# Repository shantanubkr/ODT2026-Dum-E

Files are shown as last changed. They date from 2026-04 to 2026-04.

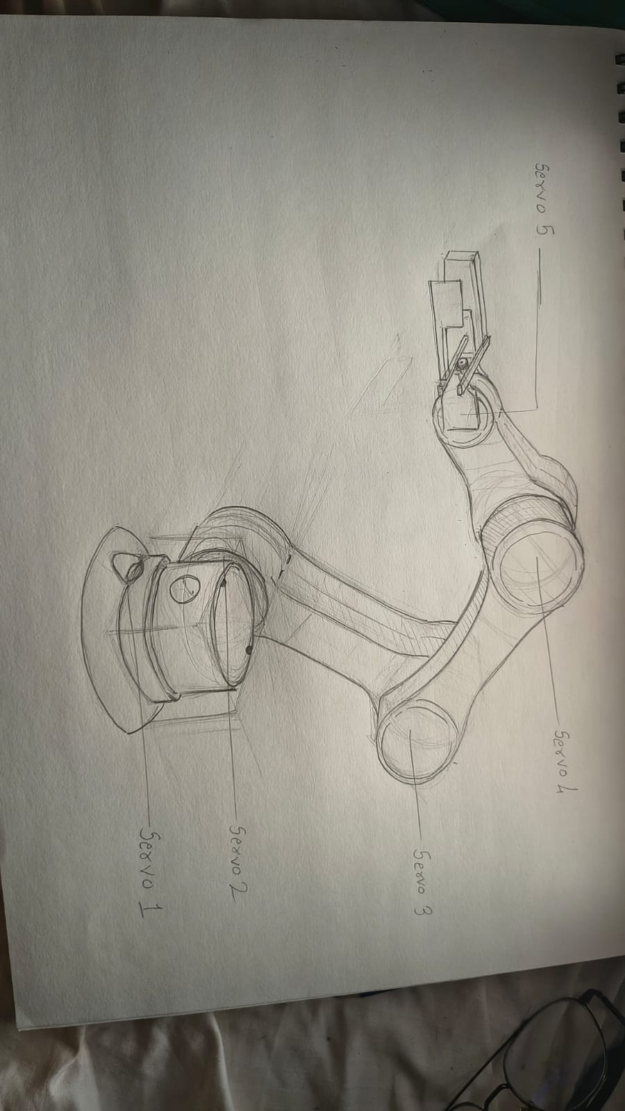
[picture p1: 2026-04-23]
Media/Week2/WhatsApp Image 2026-04-23 at 18.40.53.jpeg

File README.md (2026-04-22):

**Project Title**

dum-e

**📌 Project Overview**

Dum-E is a custom-built, articulated robotic arm.

It operates using the ROS 2 Humble software framework to handle complex kinematics and precise, multi-joint motion control. Physically, the arm is driven by a stable S-25-5 power supply to manage heavy actuator loads and features an integrated ESP32-CAM module that provides real-time visual telemetry and spatial awareness.

**📂 Repository Structure**
1. Electronics Details
2. Mechanical Details
3. Software Details
4. Project Documents
5. Media

**⚙️ How to Navigate This Repository**

Electronics Details → Circuit, components justification

Mechanical Details → Sketches, CAD, and fabrication

Software Details → Code, logic, and implementation

Project Documents → Design thinking, planning, testing

Media → Weekly progress and final output

**👥 Team Members**
Avyukt and shantanu

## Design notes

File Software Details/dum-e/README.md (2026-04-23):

# DUM-E

DUM-E is an ESP32-based robotic arm / assistant inspired by Marvel’s DUM-E. On-robot: **ESP32**, **five servos**, and **power**. **Camera and higher-level software** (dashboard, vision, optional ROS) run on a **laptop**. This repository holds the MicroPython firmware, deploy tooling, and desktop app.

The device runs **MicroPython** on an ESP32. You edit code locally in **Cursor** and deploy it to the board (for example with `mpremote` and the scripts under `deploy/`).

### Setup (host)

1. **One-shot host install** (creates `.venv`, installs `mpremote`):

   ```bash
   cd "/path/to/Software Details/dum-e"
   ./setup-host.sh
   ```

2. **Push code to the ESP32 and reset** — `deploy/common.sh` picks a serial port automatically (`DUM_E_MPREMOTE_PORT` if set and valid, else `/dev/cu.usbserial-0001`, else first `cu.usbserial*` / `wchusbserial*` / `SLAB`):

   ```bash
   cd deploy
   ./sync.sh          # same as ./upload.sh && ./run.sh
   ```

3. **Open the REPL** (quit anything else using the USB serial port first — Thonny, another `mpremote`, etc.):

   ```bash
   cd deploy
   ./repl.sh
   ```

4. **Manual split** (same as before): `./upload.sh` then `./run.sh`.

5. The scripts prefer `.venv`’s `python -m mpremote` (see `deploy/common.sh`).

6. **`mpremote: failed to access (it may be in use…)`** — another app has the port, **or** `DUM_E_MPREMOTE_PORT` was empty/wrong. Fix: close other serial tools, `unset DUM_E_MPREMOTE_PORT` for auto-detect, or `export DUM_E_MPREMOTE_PORT=/dev/cu.usbserial-0001`.

7. If you moved the repo and see `bad interpreter` from `mpremote`, remove `.venv` and run `./setup-host.sh` again.

8. **`termios.error: (22, 'Invalid argument')` when `mpremote` connects** — pyserial could not apply serial settings on that `/dev/cu.*` node (common on macOS with some USB‑UART chips or when the wrong device is selected). Quit the **desktop app**, **Thonny**, and any **serial monitor** using the same port; unplug/replug the ESP32; run `ls /dev/cu.*` and set **`export DUM_E_MPREMOTE_PORT=/dev/cu.…`** to the real motor board; try another **USB cable/port** (data cable, not charge‑only); update the vendor driver (Silicon Labs CP210x, WCH CH34x, etc.) for your OS version; then **`pip install -U pyserial mpremote`** in `.venv`. If **`screen /dev/cu.… 115200`** also fails, the issue is outside Python (cable, hub, or driver).

## Current focus

1. Foundation (project layout, config, docs)
2. Motion (servos, named poses, smooth stepping)
3. Safety (limits, emergency stop)
4. Vision & UX on the laptop (camera, dashboard, optional ROS)
5. Higher-level behavior (state machine, commands, personality-style behaviors)
6. **Table / pick calibration (USB `pose_deg` jog):** see **`calibration/README.md`**

## Project structure

| Path | Role |
|---|---|
| `src/` | MicroPython application: entrypoint, config, drivers, modules, interfaces |
| `docs/` | Hardware inventory, architecture, state machine notes |
| `deploy/` | Helper scripts to upload `src/` to the device and reset the board |
| `requirements.txt` | Host Python deps (`mpremote`); use with project `.venv` |

## Next steps

- Finalize wiring and tune `src/pins.py` + per-joint PWM limits in `src/config.py`.
- Calibrate motion and grow the state machine / command path as behaviors stabilize.

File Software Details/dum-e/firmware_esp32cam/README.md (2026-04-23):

# ESP32-CAM: MJPEG tuning (Arduino + reference for MicroPython)

## Arduino (`esp32-camera` / `esp_camera` init)

In your `setup()` (before `esp_camera_init(&config);`), set:

```c
config.frame_size = FRAMESIZE_QVGA;   // 320×240 — stable, low bandwidth
config.jpeg_quality = 20;             // 0–63; **higher** = more compression / smaller files (less lag)
```

Use the value `20` for a smaller per-frame payload than very low values (e.g. 5–10) which can produce **larger** JPEGs in busy scenes, depending on the sensor driver.

`jpeg_quality` semantics follow **Espressif `esp32-camera`**: see your board package’s `sensor_t` and examples under **Examples → ESP32 → Camera → CameraWebServer**.

## MicroPython (this repo)

`desktop_app/launch_cam.py` pastes a stream server that uses `camera.FRAME_QVGA` and, if supported, `quality=20` in `camera.init(...)`. If the board firmware rejects `quality=`, the script falls back to the two-argument `init` only.

## Laptop / OpenCV

Use `desktop_app/services/camera_stream.py` — **FFmpeg** backend, **buffer size 1**, corrupt frames return `None` so vision does not block on a bad chunk.

See `firmware_esp32cam/arduino_mjpeg_config_snippet.ino` for a drop-in `config` block.

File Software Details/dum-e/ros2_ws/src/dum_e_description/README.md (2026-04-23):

# dum_e_description

ROS 2 Humble package: **URDF/xacro**, **meshes**, and Gazebo extras for DUM-E (4 revolute joints; matches firmware four-DOF arm).

## Contents

| Path | Purpose |
|---|---|
| `urdf/dum-e.xacro` | Main robot (Revolute 7–10); includes materials, transmissions, Gazebo |
| `urdf/*.xacro` | Includes |
| `meshes/*.stl` | Visual/collision meshes (mm STLs, scale 0.001 in xacro) |

## Build

From repo root on Ubuntu / WSL2 (ROS 2 Humble sourced):

```bash
./scripts/build_ros.sh
```

Or from `ros2_ws/`:

```bash
source /opt/ros/humble/setup.bash
colcon build --packages-select dum_e_description
source install/setup.bash
```

## Visualize (`robot_state_publisher` + sliders + RViz)

Do **not** run this at the same time as `dum_e_state_manager` — both publish `/joint_states`.

```bash
source install/setup.bash
ros2 launch dum_e_description view_robot.launch.py
```

## Manual RViz (no launch file)

```bash
ros2 run xacro xacro $(ros2 pkg prefix dum_e_description)/share/dum_e_description/urdf/dum-e.xacro > /tmp/dum_e.urdf
ros2 run robot_state_publisher robot_state_publisher --ros-args -p robot_description:="$(cat /tmp/dum_e.urdf)"
```

## Joint ↔ mesh filenames

Meshes were renamed from informal CAD STL filenames to match the xacro:

- `Base.stl` → `base_link.stl`
- `Waist.stl` → `Waist_1.stl`
- `Upper_arm.stl` → `Upper_arm_1.stl`
- `Forearm.stl` → `Forearm_1.stl`
- `Hand.stl` → `Hand_1.stl`
- `end_effector.stl` — unused in current `dum-e.xacro` (reserved for a future tool)

## Note on ROS 1 transmissions

`dum-e.trans` uses ROS 1 `hardware_interface` names. For real Gazebo / ros2_control you’ll need to update or replace transmissions later.

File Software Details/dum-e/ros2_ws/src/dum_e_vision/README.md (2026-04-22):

# `dum_e_vision` (ROS 2)

Publishes **`geometry_msgs/Point`** on **`/dume/target_coord`**: **x, y** = blob centroid (px), **z** = contour area. Consumed by `desktop_app/track_target_node.py`.

## Modes

| Param | Gazebo / sim | Real ESP32-CAM (OpenCV) |
|---|---|---|
| `use_simulation` | `true` | `false` (default) |
| Input | `camera_image_topic` (default `/camera/image_raw`) | `stream_url` (e.g. `http://<ip>:81/stream`) |
| Drive | one callback per `sensor_msgs/Image` | timer at `publish_rate_hz` (default 10) |

## Build (ROS 2 Humble)

```bash
cd ros2_ws
source /opt/ros/humble/setup.bash
colcon build --packages-select dum_e_vision
source install/setup.bash
```

## Run

**Real camera:**

```bash
ros2 run dum_e_vision vision_node --ros-args \
  -p use_simulation:=false \
  -p stream_url:=http://192.168.1.100:81/stream \
  -p target_color:=red
```

**Gazebo (example):**

```bash
ros2 run dum_e_vision vision_node --ros-args \
  -p use_simulation:=true \
  -p camera_image_topic:=/camera/image_raw
```

Requires: **OpenCV** (`python3-opencv` / `cv_bridge`).

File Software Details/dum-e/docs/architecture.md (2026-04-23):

# Architecture

Firmware keeps **hardware** in one layer and **policy / behavior** in another. The ESP32 entrypoint stays **thin**: construct objects, `boot()`, then a `loop()` that polls serial, updates motion, behaviors, and activity timeouts.

## Repository layout (firmware)

| Path | Role |
|---|---|
| `src/main.py` | Entry: `StateMachine`, `IntentParser`, `BehaviorEngine`, `SafetyManager`, `MotionController`, `CommandRouter`; non-blocking stdin; optional physical buttons when `USE_PHYSICAL_BUTTONS` is True. |
| `src/config.py` | Timing, joint limits, PWM calibration, feature flags (e.g. `USE_PHYSICAL_BUTTONS`). |
| `src/pins.py` | GPIO for servos and optional `BTN_*` pins. |
| `src/backend/` | **`command_schema.py`** — `Actions`, `Command`. **`command_router.py`** — `CommandRouter` (routes `Command` to motion, safety, behaviors, status/history) and **`build_command_from_parse_result()`** (maps parser output to `Command`). |
| `src/modules/` | **`state_machine.py`** — `States` and transitions. **`command_parser.py`** — text → `{type, command, args}`. **`intent_parser.py`** — extends parser with **sentiment** (`GREET` / `BYE` / `HAPPY` / `SAD` / `NEUTRAL`) for expression behaviors. **`motion_controller.py`** — five PWM servos, named poses (`home`, `ready`, `down`). **`behavior_engine.py`** — idle / greeting / thinking + `express_*` behaviors. **`safety_manager.py`** — emergency stop (+ optional fault latch); `can_move()` gates motion in the router. |
| `src/drivers/` | **`servo.py`** — `Servo` (MicroPython `PWM` hobby servo). **`panel_button.py`** — `Button` (debounced) if **`USE_PHYSICAL_BUTTONS`** is enabled. Vision runs on the **laptop** (`desktop_app/`), not on the ESP32. |
| `src/utils/` | Logging, timers — no hardware imports. |
| `deploy/` | Host scripts (`mpremote`) — not flashed to the device. |

## Host / desktop (not on the ESP32)

| Path | Role |
|---|---|
| `desktop_app/` | Dashboard and **`dum_e_runtime.py`**: imports the same `backend` + `modules` under CPython (with a small time shim), optional **`LaptopMotionController`** sim, or **`RobotBridge`** to publish string commands to ROS 2 (`/dum_e_command`) when not skipping ROS. |
| `desktop_app/services/robot_bridge.py` | **`RobotBridge`** — maps high-level `Command` to **BLE NUS** ( **`DUM_E_BLE=1`** ), **or** USB serial ( **`DUM_E_SERIAL_PORT`** ), **or** ROS `ros2 topic pub` on **`/dum_e_command`** (one path); **not** flashed to the ESP32. |

## Data flow (firmware)

1. **stdin line** → `IntentParser.parse()` → sentiment may run **`BehaviorEngine.run_behavior()`** for `express_*` → **`build_command_from_parse_result()`** → **`CommandRouter.route()`**.
2. **`MotionController.update()`** each loop tick interpolates toward target angles (smooth motion).
3. **`BehaviorEngine.update()`** runs the current behavior tick (expressions, timed greeting/thinking).
4. **`update_activity_state()`** (firmware) or **`_update_desktop_inactivity()`** (desktop) moves **ACTIVE → SLEEP** after **`SLEEP_TIMEOUT_MS`**; activity resets the timer. There is no intermediate **IDLE** machine state.

## Principles

1. **Drivers** talk to GPIO/PWM only; they do not encode “why” the arm moves.
2. **Modules + backend** encode commands, safety, and behaviors.
3. **`main.py`** wires objects and runs the loop — minimal logic.

New on-robot hardware belongs in `src/drivers/`; new command or policy behavior in `src/modules/` or `src/backend/` as appropriate.

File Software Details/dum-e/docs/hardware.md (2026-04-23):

# Hardware inventory

This doc matches the **current build**: **ESP32**, **four PWM servos** (arm only), **dedicated servo power**, and a **camera** used with **laptop-side** vision (`desktop_app/`). CAD / ROS URDF and meshes: **`ros2_ws/src/dum_e_description/`** (canonical).

**CAD vs firmware:** The URDF has **four** revolute joints (`Revolute 7`–`10`); firmware joint order matches (**waist**, **upper_arm**, **forearm**, **hand**).

Update the **Status** column as you wire and test: `planned` → `wired` → `tested`.

---

## Controllers & compute

| Component | Qty | Notes | Status |
|---|-----|---|---|
| ESP32 DevKit (e.g. 30-pin) | 1 | MicroPython; PWM to servos; USB serial for deploy and dashboard | planned |
| Laptop | 1 | Dashboard, speech, vision, optional ROS — not on the robot PCB | planned |

---

## Motion — four PWM servos (arm)

Firmware uses **four** hobby servos (50 Hz) for the arm. The **base** link in CAD has **no motor**; rotation starts at **waist**.

| Servo # | Firmware / CAD name | Role |
|---|---|---|
| 1 | `waist` | Base rotation (base ↔ waist) |
| 2 | `upper_arm` | Waist ↔ upper arm |
| 3 | `forearm` | Upper arm ↔ forearm |
| 4 | `hand` | Forearm ↔ hand (wrist) |

Joint order in code and logs: `waist`, `upper_arm`, `forearm`, `hand`.

| Component | Qty | Notes | Status |
|---|-----|---|---|
| Hobby / RC servo (PWM), arm | 4 | Per link torque | planned |

GPIO defaults are in `src/pins.py` (`SERVO_WAIST`–`SERVO_HAND`, or PCA9685 channels when `USE_PCA9685` is True). **Change there when wiring is final.**

Mechanical **upright / home** is defined in `src/config.py` as **`UPRIGHT_POSE_DEG`** (and `robot_kinematics.UPRIGHT_FIRMWARE_DEG`): by default all joints **90°** after PWM calibration so the arm stands stacked neutral.

**Control:** Default build has **no** physical panel buttons (`USE_PHYSICAL_BUTTONS = False` in `config.py`). Use **desktop dashboard**, **USB serial**, or **REPL**.

---

## Power

| Component | Qty | Notes | Status |
|---|-----|---|---|
| USB cable / 5 V from host | 1 | Powers and programs the ESP32 | planned |
| 5 V rail for servos (bench supply, BEC, or buck) | 1 | Servos draw high peak current; **do not** power servos from the ESP32 3.3 V regulator | planned |
| Common ground | 1 | ESP32 GND tied to servo supply GND for valid PWM | planned |
| Buck / LDO (optional) | 0–1 | If logic runs from a higher-voltage main rail | planned |

---

## Camera & vision

| Component | Qty | Notes | Status |
|---|-----|---|---|
| Camera module (e.g. USB webcam or board-mounted module) | 1 | Feeds the **laptop**; processing lives in `desktop_app/` (OpenCV, optional idle look-at). **ESP32 firmware does not run vision.** | planned |

---

## Passive, mechanical, prototyping

| Component | Qty | Notes | Status |
|---|-----|---|---|
| Capacitors | as needed | Bulk/decoupling on servo supply if long leads or noisy supply | planned |
| Resistors | as needed | e.g. pull-ups if you add I2C later | planned |
| Jumper wires | — | Dupont / solid core | planned |
| Breadboard / perfboard | — | Bring-up | planned |

---

## ROS / simulation (not on the robot PCB)

| Item | Notes |
|---|---|
| `ros2_ws/src/dum_e_description/` | Canonical URDF, meshes, launch for RViz |
| `dum-e.trans` | ROS 1–style transmissions; replace with **ros2_control** if you simulate in Gazebo later |

---

## Components table (electronics documentation)

| Component | Quantity | Purpose | Justification |
|---|---|---|---|
| ESP32 development board | 1 | Run MicroPython, PWM for servos, USB for programming and serial dashboard | Single board with enough GPIO; matches firmware and deploy flow (`mpremote`). |
| Hobby (RC) servo motors | 4 | Arm joints (waist … hand) | PWM servos per mechanical design. |
| 5 V power source for servos | 1 | Supply motor current without loading the ESP32 regulator | Peak current; dedicated rail avoids brownouts. |
| Common electrical ground | 1 (net) | ESP32 GND to servo supply GND | Required for valid PWM references. |
| USB cable | 1 | Power and flash ESP32 from PC | For `deploy/` scripts and REPL. |
| Camera (with laptop) | 1 | Vision / idle behaviors on host | Processing in `desktop_app/`, not on ESP32. |
| Jumper wires / breadboard | as needed | Bring-up | Standard prototyping. |

---

## Placeholders

Add rows for **panel buttons**, **E-stop**, **encoders**, or **LEDs** only if those become part of the wired build.

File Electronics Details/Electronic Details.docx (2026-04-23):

# Electronics Documentation

### 1. Electronics Block Diagram

Show signal and power flow

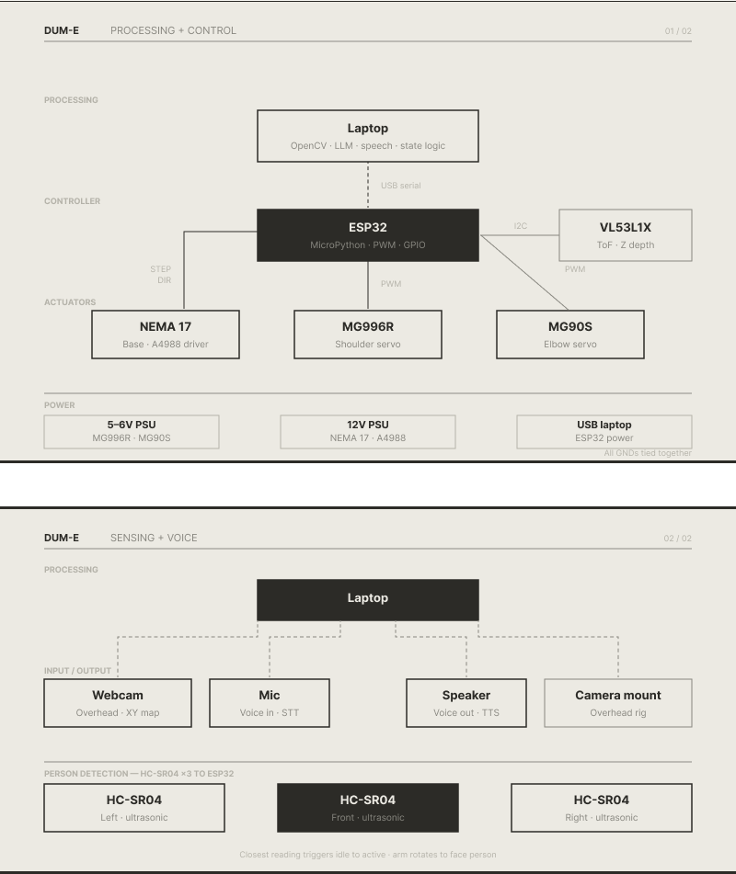
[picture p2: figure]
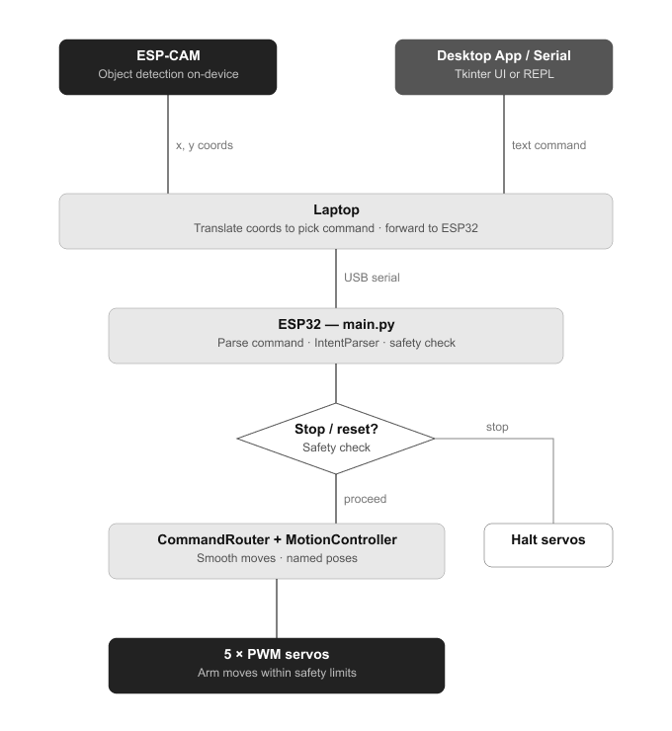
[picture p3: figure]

### 2. Components Table

Component | Quantity | Purpose | Justification
ESP32 development board | 1 | Run MicroPython, PWM for five servos, USB for programming and serial control | One MCU with enough GPIO for five PWM channels and USB; matches firmware and deploy workflow.
servo motors: mg996R Mg90s sg90s | 5 | Move waist, upper arm, forearm, wrist, and gripper | Settable angles per joint for a small arm
Jumper wires / breadboard | As needed | Prototype connections before final harness | Standard for lab wiring and iteration.
5v Power Supply | 1 | To power the components | Required for energy
PCA9685 | 1 | To control the servos without fluctuations | Required for the servos to avoid current fluctuations
Esp 32 cam | 1 | To map the objects on the table | Required to map the surface and object detection

Justification is important

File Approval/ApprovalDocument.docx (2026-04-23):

ODT Summative 2

Idea Brief :

DUM-E is an interactive robotic arm inspired by the Iron Man assistant, designed to respond to natural voice commands and interact with its surroundings in a human-like manner. The system combines speech recognition, computer vision, and robotic motion to create an intuitive and engaging user experience.

Users can speak to DUM-E in complete sentences (e.g., “pick up the red object” or “go home”), which are processed using local speech-to-text and interpreted into actionable commands. A top-mounted camera detects objects on the workspace using color-based vision, identifies their position, and maps them to real-world coordinates. The robotic arm then moves precisely to the object, picks it up, and performs the required action.

Beyond task execution, DUM-E is designed to feel expressive and interactive. It reacts to greetings, commands, and user behavior through movement and sound-based feedback, creating a personality-driven interaction rather than a purely functional system.

The goal of this project is to build a system that seamlessly integrates voice interaction, perception, and motion into a cohesive robotic assistant that is both functional and engaging.

Basic Idea Sketch :

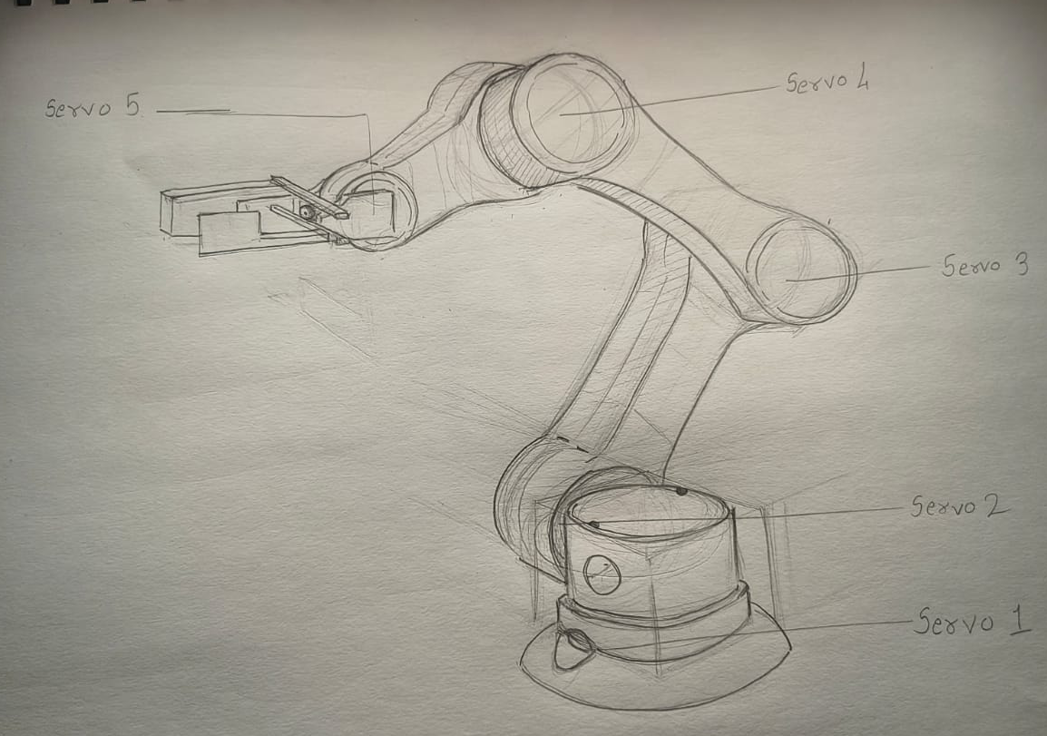
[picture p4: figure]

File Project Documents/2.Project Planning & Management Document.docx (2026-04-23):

# Project Planning & Management Document

### 1. Project Overview

- Project Title: Dum-E
- Team Members & Roles:
  - Shantanu Borkar - Software Guy
  - Avyukt Srivastava - Hardware Guy
- Brief Description (2–3 lines)
  - DUM-E is an interactive robotic arm that responds to natural voice commands and uses a camera to detect and locate objects in its workspace. It combines speech recognition, computer vision, and motion to perform actions like picking and placing objects. The system focuses on creating an intuitive and engaging human-robot interaction experience.

### 2. Team Roles & Responsibilities

Member Name | Role | Responsibilities
Shantanu Borkar | Software Guy | Designed the overall system architecture (voice → vision → motion) Built the desktop app for interaction and control Implemented speech-to-text and command interpretation Developed color-based object detection using the camera Integrated command routing with the robot hardware Tested, debugged, and ensured system stability
Avyukt Srivastava | Hardware Guy | Designed and modeled the robotic arm components (3D design and sizing) 3D printed parts and handled assembly of the full structure Defined joint dimensions, ranges, and mechanical mapping Integrated servo motors, gripper mechanism, and physical joints Set up and connected ESP32 and ESP32-CAM hardware Managed wiring, power distribution, and overall hardware testing and calibration

👉 Clearly define who is responsible for what (software, electronics, documentation, etc.)

### 3. Project Timeline & Milestones

Week | Goals | Deliverables | Status
Week 0 | Finalize project idea and scope Define system architecture (voice, vision, motion) Split roles (software / hardware) | Idea brief and architecture plan Basic hardware and software requirements list | Completed
Week 1 | Set up robotic arm hardware base Build initial desktop app structure Implement basic command flow (manual / button-based) | Working robotic arm (basic movement) Initial software framework and control interface | Completed
Week 2 | Integrate speech-to-text for voice commands Build AI interpreter for command parsing Set up camera and implement color-based object detection | Voice-controlled commands working Camera detecting objects and returning coordinates | Completed
Week 3 | Integrate vision with motion (pick object flow) Add sound-based feedback and interaction polish Test full pipeline (voice → detection → action) | End-to-end working system Stable interaction and demo-ready prototype | Not completed

👉 Break project into weekly achievable goals

### 4. Weekly Progress Log

### Week 0

Planned Tasks:

- Finalize idea and system architecture
- Define roles and required components

Completed Tasks:

- Decided on DUM-E concept (voice + vision + motion)
- Designed overall system flow
- Listed hardware and software requirements

Challenges Faced:

- Scope was initially too broad (wanted too many features)

Solutions:

- Reduced scope to core features: voice control + object detection + pick action

Next Steps:

- Start hardware build and basic software setup

### Week 1

Planned Tasks:

- Build robotic arm structure
- Set up initial software control

Completed Tasks:

- Designed and 3D printed arm parts
- Assembled basic arm structure
- Set up ESP32 and basic motor control
- Created initial desktop app structure

Challenges Faced:

- Planned to use a stepper motor for 360° base rotation but it wasn’t ordered in time

Solutions:

- Switched to using a servo-based setup for the base instead

Next Steps:

- Improve control system and start integrating interaction

### Week 2

Planned Tasks:

- Implement voice commands
- Set up camera and object detection
- Work on coordinate mapping

Completed Tasks:

- Integrated local speech-to-text (Whisper)
- Built AI interpreter for commands
- Implemented basic color-based detection
- Created digital simulations for object picking and coordinate mapping

Challenges Faced:

- Voice commands initially didn’t work reliably with natural sentences
- Coordinate mapping and simulated pick actions were inconsistent

Solutions:

- Improved interpreter logic to handle full sentences instead of exact keywords
- Refined mapping logic and tested through simulations instead of hardware

Next Steps:

- Connect vision with motion and stabilize the full pipeline

### Week 3

Planned Tasks:

- Integrate all systems (voice → vision → motion)
- Test full working prototype
- Add interaction feedback

Completed Tasks:

- Built end-to-end pipeline in software (voice → detect → action)
  - Action failed
- Added sound-based feedback for interaction
- Finalized system for demo

Challenges Faced:

- Physical testing was delayed; most testing was done digitally until the last day
- Could not implement additional sensors (ultrasonic/LDR) for distance detection due to time constraints
- Limited time for real-world calibration and tuning

Solutions:

- Focused on ensuring digital pipeline worked reliably
- Simplified features to ensure core system was functional

Next Steps:

- Improve physical testing, calibration, and sensor integration in future iterations

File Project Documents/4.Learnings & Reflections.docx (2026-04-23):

# Learnings & Reflections Document

## 1. Team Reflection

How did the team work together?
The team had clear role distribution, with members focusing on hardware, software, and integration. Collaboration was strong during building phases, but less consistent during testing and validation.

What worked well?

- Clear division of responsibilities
- Fast execution and willingness to build quickly
- Good problem-solving when issues were identified

What could be improved?

- Lack of continuous testing throughout development
- We kept adding features instead of validating what was already built
- Poor integration planning between hardware and software
- Needed more structured checkpoints instead of last-minute fixes

## 2. Technical Reflection

Key technical challenges

- Servo motors behaving unpredictably due to signal and power issues
- System instability when multiple components were connected
- Voice commands not functioning reliably
- Difficulty in coordinate mapping and object pickup logic
- Final system integration failing under real conditions

What did you learn (hardware/software)?

- Testing individual components early is critical
- Hardware systems require stable power and clean signal separation
- Building multiple features without validation leads to system failure
- Integration is harder than building individual parts
- Real-world performance is very different from isolated testing

Mistakes & debugging experiences

- Biggest mistake: delaying testing until the end
- We kept stacking features without checking if the system still worked
- Debugging became overwhelming because too many things were broken at once
- We learned that small, incremental testing is far more effective than final-stage debugging

## 3. Design Reflection

Did the experience match your intention?
No. While the concept was strong, the final system did not perform as expected during the presentation due to lack of proper testing and refinement.

What would you improve?

- Follow a build → test → iterate cycle instead of continuous feature addition
- Prioritize reliability over adding new features
- Test in real-world conditions earlier, not just controlled setups
- Simplify the system before scaling complexity

User feedback insights

- The idea was appreciated, but execution felt incomplete
- Inconsistent behavior reduced confidence in the system
- A simpler but reliable system would have created a stronger impact

## 4. Personal Reflection

### Shantanu Borkar

  - What I learned I learned how to break down a robotics system into smaller working parts instead of trying to build everything at once. On the software side, I worked on writing control logic for servos using PWM and handling multiple actuators together. I also explored integrating features like text to speech for command feedback, basic coordinate mapping for movement logic, and object detection using the ESP32-CAM module.

I understood how important signal stability, proper grounding, and power distribution are when working with multiple servos and sensors. I also learned that hardware and software cannot be treated separately, both need to be tested together from early stages.

  - What I struggled with I struggled with scope control and kept adding features like voice input, object detection, and mapping without fully stabilizing the base system. This led to multiple issues stacking up at the same time.

Technically, I faced problems with servo jitter and unintended movements due to shared power lines and noisy signals. Integrating ESP32-CAM for object detection was also difficult because of limited processing and inconsistent outputs. The biggest challenge was system integration, getting all components like servos, camera, and logic to work together reliably.

  - What I am proud of I am proud that I took ownership of the system logic and kept pushing through technical issues instead of simplifying the project. I worked on implementing text to speech output, attempted coordinate-based movement, and integrated ESP32-CAM for object detection as part of the system.

Even though the final system was not stable during the presentation, I built and tested multiple complex components and understood where and why they failed. I now have a clearer understanding of real world constraints like power limitations, signal interference, and the importance of iterative testing in system design.

- Avyukt Srivastava
  - What I learned I learned how to structure a robotics system using ROS2 Humble by dividing it into different packages like dum_e_description, dum_e_controller, and dum_e_hardware. I also learned how to use colcon to build and manage these packages properly. Along with this, I gained practical experience in connecting software with hardware, including working with the ESP32-CAM module for vision and understanding how to manage power across the system.
  - What I struggled with I faced challenges with the power supply, especially while troubleshooting the S-25-5 unit to make sure it was providing stable voltage. I also struggled with the connection between hardware and software. Making sure ROS2 controllers could communicate properly with the physical components took a lot of debugging and testing.
  - What I am proud of I am proud that I was able to get all the main parts of the system working together, including the hardware, description, and controller packages. I also feel proud of building a strong base for the Dum-E project, taking it from just an idea to a working system that can be improved further.

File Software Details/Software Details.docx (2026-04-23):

# Software Documentation

## 1. Software overview

What the software does

- On the ESP32: Runs MicroPython firmware that reads text commands (USB serial), parses them, applies safety (e.g. stop/reset), updates a state machine, runs behaviors (idle, greetings, short “expression” motions), and drives five PWM servos through a motion controller (smooth moves to targets and named poses like home / ready / down).
- On the laptop (optional): A Python desktop app (Tkinter UI) sends the same style of commands to the board over USB serial and can optionally forward high-level actions to ROS 2 for coordination/visualization.
- ROS 2 (optional, Linux/WSL): URDF/meshes and tools like RViz describe and visualize the arm; they do not replace firmware on the robot.

Platforms & languages

Layer | Platform / stack
Robot firmware | MicroPython on ESP32
Deploy / REPL | Host Python 3 + `mpremote` (scripts under `deploy/`)
Desktop UI | CPython 3 + Tkinter (`desktop_app/`)
Simulation / viz | ROS 2 (e.g. Humble) + URDF/xacro (`ros2_ws/`) — optional

Not used in this codebase: MIT App Inventor, Bluetooth/BLE app path (control is USB serial by default).

## 2. System logic (simple flow)

Typical path: user uses the desktop app

1. User types a command or uses a control in the DUM-E Desktop app.
2. The app sends a line of text to the ESP32 over the USB serial port (same as typing into a serial terminal).
3. `main.py` reads the line; `IntentParser` classifies it (and may detect sentiment for expression motions).
4. `build_command_from_parse_result()` builds a `Command`; `CommandRouter` runs it (move home, pick/place poses, stop, reset, status, etc.).
5. `MotionController.update()` each loop tick moves servos toward targets; `BehaviorEngine.update()` runs timed/expression behaviors.
6. Servo PWM updates → arm moves (within software limits).

Typical path: direct serial / REPL (no desktop app)

7. User connects with `mpremote`, Thonny, or any serial monitor.
8. User sends a line ending in Enter.
9. Steps 3–6 are the same as above.

Optional: ROS bridge (when enabled on the laptop)

- The desktop runtime may map some commands to ROS 2 topic publishes (e.g. string commands for a state manager node), while the physical arm still follows firmware when the ESP32 is connected.

## 3. Flowchart (visual)


## 4. App flow — MIT App Inventor

Not applicable. This project does not use MIT App Inventor.

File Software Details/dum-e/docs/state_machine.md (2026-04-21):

# State machine

States are defined in **`src/modules/state_machine.py`** as **`States.*`** string constants. Use **`change_state()`** for transitions (logged); do not assign raw strings.

## States

| State | Meaning in code |
|---|---|
| `BOOT` | Initial value after `StateMachine()`; cleared on first **`boot()`** in `main.py` (or desktop init in **`dum_e_runtime.py`**) by transitioning to **`ACTIVE`**. |
| `ACTIVE` | Default “awake” running state after boot; user activity keeps the activity timer fresh. While behavior is **`"idle"`**, **`BehaviorEngine`** runs **curious wander** (motion every 2–5 s) when **`SafetyManager.can_move()`** allows. |
| `SAD` | **Mood** state after negative sentiment: **`express_sad`** animation, then **`sad_hold`** (slouch). No wander. Exits to **`ACTIVE`** on almost any routed command (except **`status`** / **`history`**) or on **GREET** / **HAPPY** / **BYE** sentiment. |
| `WORKING` | Set by **`CommandRouter`** for **`MOVE_TO`** when there is **no** named pose in metadata — placeholder path (“trajectory TBD” in logs). |
| `ERROR` | Legacy / reserved; **`STOP`** no longer lands here — use **`STOP_COOLDOWN`**. |
| `STOP_COOLDOWN` | After **`STOP`**: move to **`home`**, then when home is reached **`trigger_emergency_stop()`** and hold **10 s** (`STOP_COOLDOWN_MS`) with **no** other motion or commands (duplicate **`STOP`** ignored). Then estop clears automatically → **`ACTIVE`** + **`idle`** (wander enabled again). |
| `DATA_ERROR` | Bad serial / timeout / coords: call **`CommandRouter.route_data_fault(reason)`** — log, **`error_nod`** (waist shake), stub error sound log; **5 s** later (`DATA_ERROR_RECOVERY_MS`) auto **home** → **`ACTIVE`** + **`idle`**. Other commands ignored until recovery or **`RESET`**. |
| `SLEEP` | Entered when **`SLEEP_TIMEOUT_MS`** passes since last activity (unless already sleeping). **`STOP_COOLDOWN`**, **`DATA_ERROR`**, and **`ERROR`** return early so sleep logic does not run. There is **no separate `IDLE` state** — inactivity goes straight to **sleep**. |

## Behaviors tied to states (related, not 1:1)

- **`SLEEP`**: `BehaviorEngine` is set to **`"none"`** (no wander).
- **`ACTIVE`** with behavior **`"idle"`**: curious wander + optional **`idle_look_at`** inspect (vision / `IDLE_LOOK_AT` command).
- **`RESET`**: clears estop and fault timers, transitions to **`ACTIVE`**, behavior **`"idle"`**, arm to **`home`** pose.

## Commands that change state (via `CommandRouter`)

| Action | Typical transition |
|---|---|
| `STOP` | → **`STOP_COOLDOWN`**, move **`home`**, then 10 s hold at home (estop); then auto **`ACTIVE`** + **`idle`**. Second **`STOP`** during hold is ignored. |
| `RESET` | → **`ACTIVE`**, estop off, fault timers cleared, `home` |
| `GREET` | → **`ACTIVE`**, **`greeting`** behavior (move to **home** pose, **hand nod**, then **`idle`**) |
| `dance` | → **`ACTIVE`**, **`dancing`** behavior (rhythmic sway ~**`DANCE_DURATION_MS`**, then **`idle`**) |
| `MOVE_TO` (no pose) | → **`WORKING`**, thinking behavior (trajectory still TBD in router) |
| `idle_look_at` | Stays **`ACTIVE`**; **`begin_idle_inspect(waist, hand)`** if behavior is **`"idle"`** |

## Activity timer

**`mark_activity()`** resets the inactivity clock on commands (firmware **`main.py`**, desktop **`dum_e_runtime.mark_activity()`**). Waking from **`SLEEP`** on new input sets **`ACTIVE`** and **`idle`** behavior.

Desktop **`DesktopAppRuntime.send_text_command()`** calls **`mark_activity()`** so voice/text is heard even when the phrase does not parse to a routed action.

See **`src/config.py`** for **`SLEEP_TIMEOUT_MS`**, **`STOP_COOLDOWN_MS`**, **`DATA_ERROR_RECOVERY_MS`**, and wander tuning (**`IDLE_WANDER_*`**, **`IDLE_INSPECT_*`**).

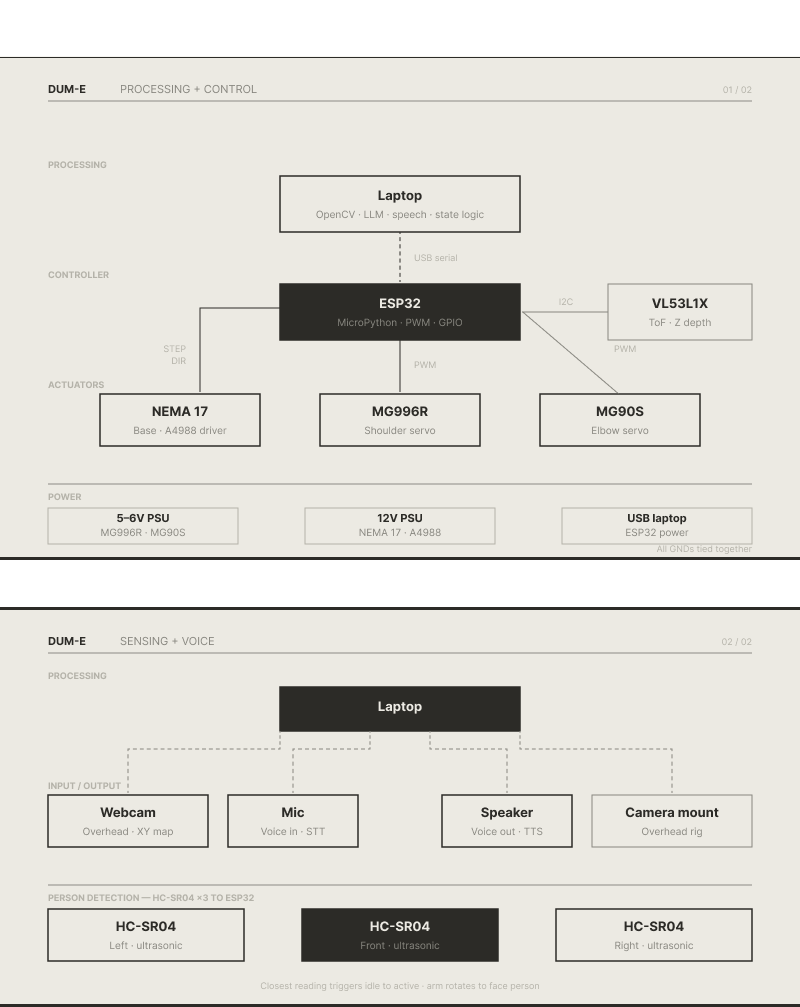
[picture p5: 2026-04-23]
Media/Week1/Group 1.png

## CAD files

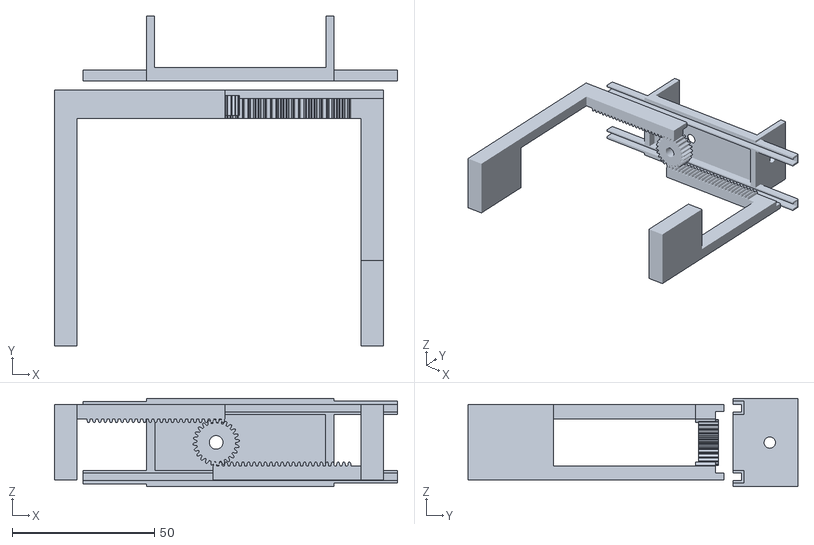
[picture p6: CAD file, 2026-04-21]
Software Details/dum-e/ros2_ws/src/dum_e_description/meshes/end_effector.stl
120.6 x 116.0 x 31.1

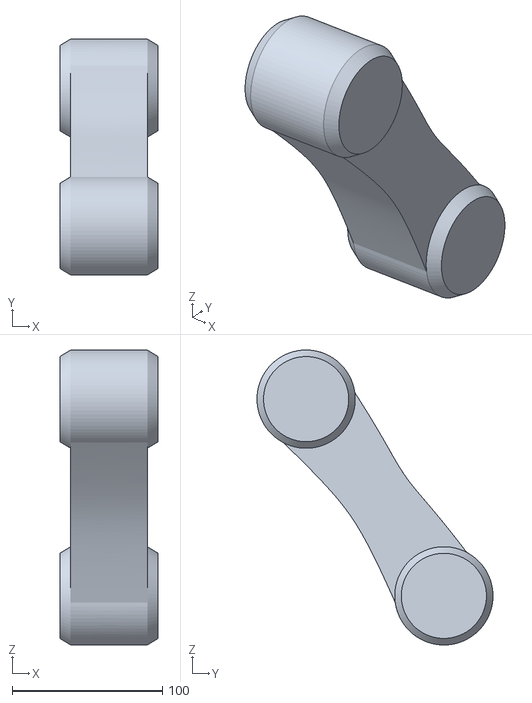
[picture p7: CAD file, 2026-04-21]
Software Details/dum-e/ros2_ws/src/dum_e_description/meshes/Forearm_1.stl
65.6 x 157.3 x 196.6

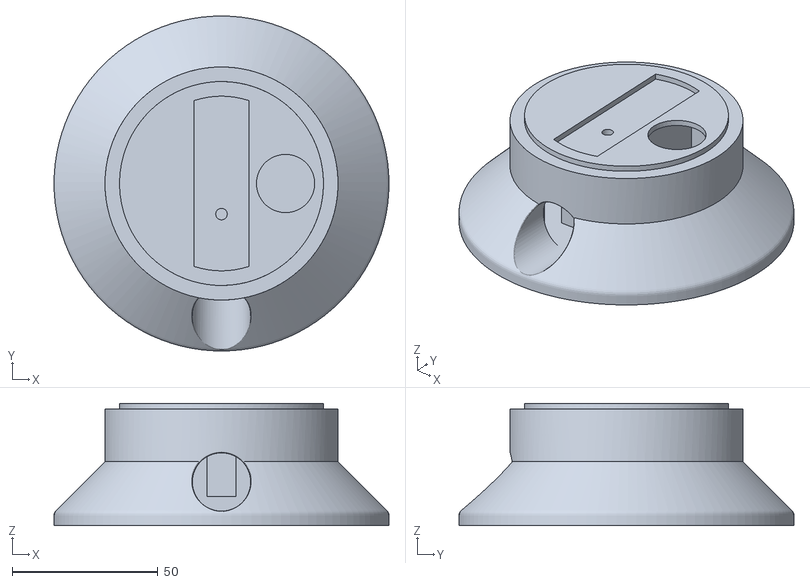
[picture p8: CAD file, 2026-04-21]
Software Details/dum-e/ros2_ws/src/dum_e_description/meshes/base_link.stl
115.0 x 115.0 x 42.0

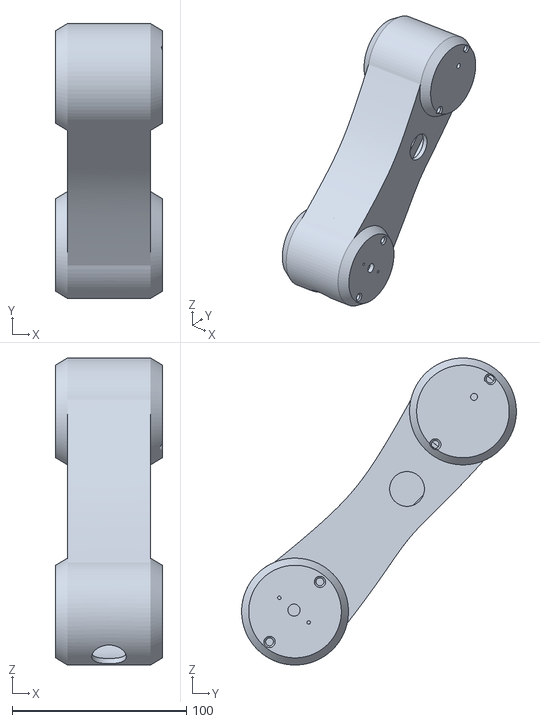
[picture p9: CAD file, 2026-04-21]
Software Details/dum-e/ros2_ws/src/dum_e_description/meshes/Upper_arm_1.stl
61.4 x 157.8 x 176.3

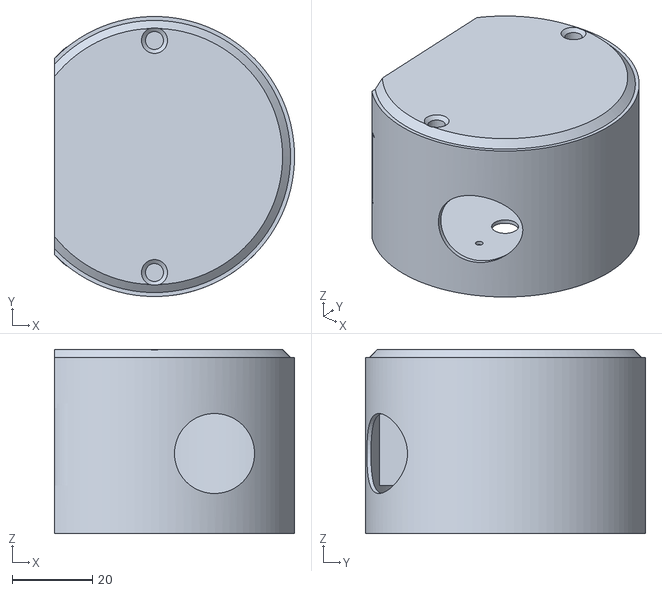
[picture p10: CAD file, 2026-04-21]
Software Details/dum-e/ros2_ws/src/dum_e_description/meshes/Waist_1.stl
60.0 x 70.0 x 46.0

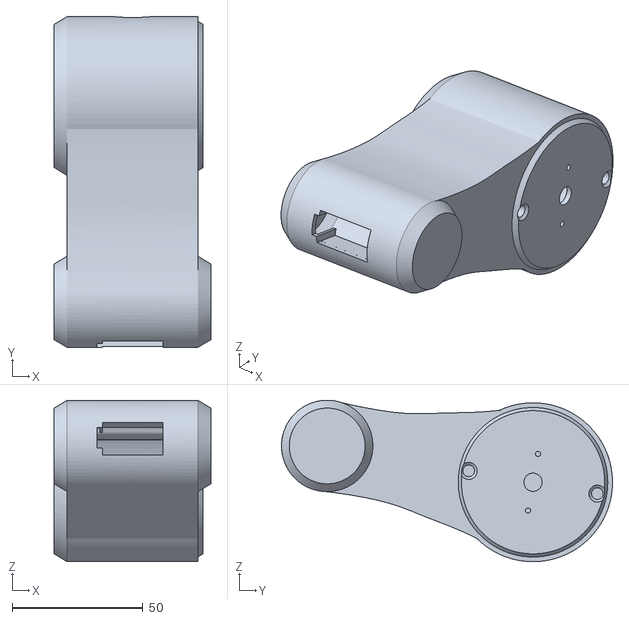
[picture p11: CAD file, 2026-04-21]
Software Details/dum-e/ros2_ws/src/dum_e_description/meshes/Hand_1.stl
60.0 x 126.7 x 61.8

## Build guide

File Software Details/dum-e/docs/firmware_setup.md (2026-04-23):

# Firmware setup & tuning (ESP32 / MicroPython)

Matches the **servo-only** build in **`src/modules/motion_controller.py`** and **`src/drivers/servo.py`** (`Servo` class). Default: **no panel buttons** — control via **desktop dashboard**, **USB serial**, or **REPL** (`USE_PHYSICAL_BUTTONS = False` in **`src/config.py`**).

## What to configure

| Location | Purpose |
|---|---|
| `src/pins.py` | GPIO per servo (`SERVO_*`); optional `BTN_*` if using physical buttons. |
| `src/config.py` | **`UPRIGHT_POSE_DEG`** / **`JOINT_HOME_ANGLES`**, **`MOTION_SMOOTHING`**, **`MOTION_DEADZONE_DEG`**, `LOOP_DELAY_MS`, `USE_PHYSICAL_BUTTONS`, **`USE_BLE_NUS`**, per-joint **`JOINT_ANGLE_*`**, **`SERVO_PWM_MIN_US` / `SERVO_PWM_MAX_US`**, idle look ranges, sleep timeouts, behavior durations. |

## After mechanical assembly

1. **GPIOs / PCA** — Confirm **`pins.py`** matches wiring (legacy GPIO defaults: waist 4, upper_arm 22, forearm 23, hand 21; or I2C + PCA9685 per the same file).
2. **PWM calibration** — For each joint, sweep toward **0°** and **180°** and tune **`SERVO_PWM_MIN_US[i]`** / **`SERVO_PWM_MAX_US[i]`** so horns match mechanical limits without binding (often 500–2500 µs; some servos need a narrower range).
3. **Software limits** — Set **`JOINT_ANGLE_MIN_DEG`** / **`JOINT_ANGLE_MAX_DEG`** so commands never exceed **physical stops**.
4. **Motion feel** — Increase **`MOTION_SMOOTHING`** (0.05–0.2) for snappier tracking to targets; lower **`LOOP_DELAY_MS`** raises the loop rate (smoother but more CPU). **`MOTION_DEADZONE_DEG`** reduces end-stop jitter.

## Physical buttons (optional)

Set **`USE_PHYSICAL_BUTTONS = True`** in **`config.py`**. **`main.py`** then uses **`drivers.panel_button.Button`** on **`BTN_J1`…`BTN_J4`** (joint select) and **`BTN_UP` / `BTN_DOWN`** (nudge).

## Commands (stdin / dashboard)

Parsed by **`modules/command_parser.py`** (exact keywords) and **`modules/intent_parser.py`** (adds **sentiment**). Known one-word commands include: **`pick`**, **`drop`**, **`move`**, **`stop`**, **`hello`**, **`home`**, **`ready`**, **`down`**, **`status`**, **`history`**, **`reset`**. Lines like **`move left`** are parsed as **`move`** with args.

**`build_command_from_parse_result()`** in **`backend/command_router.py`** maps parser output to **`Command`** + **`Actions`**. **`STOP`** / **`RESET`** interact with **`SafetyManager`** and **`StateMachine`** as documented in **`docs/state_machine.md`**.

Sentiment keywords can trigger **`express_*`** behaviors in **`main.py`** before routing (see **`_SENTIMENT_BEHAVIOR`** map).

## Laptop / ROS / RViz

- **Inverse kinematics**, measured link lengths, and **URDF** live on the host; see **`ros2_ws/src/dum_e_description/`** and **`docs/hardware.md`**.
- **Without ROS (e.g. Mac only):** set **`DUM_E_SERIAL_PORT`** to the motor ESP’s USB device (for example `DUM_E_SERIAL_PORT=/dev/cu.usbserial-0001`). **`desktop_app/services/robot_bridge.py`** then sends the same one-line text commands over **USB serial** only — it will **not** also run `ros2 topic pub`. Optional **`DUM_E_SERIAL_BAUD`** (default `115200`). Close **`mpremote`** / Thonny while the app owns the port.
- **BLE (Nordic UART):** on the ESP32 set **`USE_BLE_NUS = True`** in **`config.py`** (needs a **MicroPython build with Bluetooth**). On the laptop: **`DUM_E_BLE=1`**, **`pip install bleak`**, optional **`DUM_E_BLE_NAME`** / **`DUM_E_BLE_ADDRESS`** (same NUS UUIDs as common ESP32 examples). Unset **`DUM_E_SERIAL_PORT`** when using BLE so the bridge does not open USB. USB serial + BLE can both feed **`main.py`** if you still plug in USB for logs, but the desktop should use only one transport.
- **With ROS:** leave **`DUM_E_SERIAL_PORT` unset** and do **not** set **`DUM_E_SKIP_ROS2=1`**. The bridge publishes to **`/dum_e_command`**. Do not enable **`DUM_E_LOCAL_TARGET_TRACK`** in **`desktop_app`** at the same time as the ROS **`track_target_node`**.
- **Dry run (logs only):** set **`DUM_E_SKIP_ROS2=1`** and **no** serial port — no bytes to the robot.

## Serial / dashboard

The main loop reads **lines from stdin** (USB serial). The desktop app is intended to send the same text commands as the REPL. Ensure **`main.py`** is the entry script on the board after deploy.

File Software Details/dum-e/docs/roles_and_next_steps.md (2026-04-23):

# DUM-E — repo map & follow-ups

## In repo today

| Area | Contents |
|---|---|
| **`ros2_ws/src/dum_e_description/`** | ROS 2 package: URDF/xacro, meshes, **`launch/view_robot.launch.py`** (`robot_state_publisher` + joint GUI + RViz — see package README). |
| **`ros2_ws/src/dum_e_vision/`** | **`vision_node`**: Gazebo **`Image`** or real **HTTP MJPEG** → **`/dume/target_coord`** (`Point`: x,y,z=area). See package **README**. |
| **`src/`** | ESP32 MicroPython firmware: servos, parser, router, behaviors, safety. |
| **`desktop_app/`** | Dashboard + CPython runtime bridging **`CommandRouter`** and optional **`RobotBridge`** (ROS 2). |

## ROS / simulation follow-ups (software)

| Task | Notes |
|---|---|
| Joint name mapping | URDF uses names like **`Revolute 7`–`10`**; firmware uses **`waist`**, **`upper_arm`**, etc. Bridge or rename in **`dum_e_controller`** / RViz as needed. |
| `/joint_states` vs firmware | **`dum_e_state_manager`** publishes four URDF joints; names map from logical waist/upper/forearm/hand (see package). |
| **`dum_e_state_manager`** | Align with live topic names and **`dum_e_description`** after testing on a ROS machine. |
| Gazebo / **ros2_control** | **`dum-e.trans`** is legacy-style; replace when you add proper simulation. |

## Hardware / CAD (coordination)

| Task | Notes |
|---|---|
| STLs / meshes | **Done** in **`dum_e_description/meshes/`** per current CAD. |
| Future CAD changes | Re-export meshes + xacro and merge into **`dum_e_description`**. |
| Wiring / power | Physical; tracked in **`docs/hardware.md`**. |

## Quick build check (ROS 2 Humble)

```bash
cd ros2_ws
source /opt/ros/humble/setup.bash
colcon build --packages-select dum_e_description
source install/setup.bash
ros2 pkg prefix dum_e_description
```

Optional visualization:

```bash
source install/setup.bash
ros2 launch dum_e_description view_robot.launch.py
```

Do **not** run that launch at the same time as another node that also publishes **`/joint_states`** unless you intend to (see **`dum_e_description/README.md`**).

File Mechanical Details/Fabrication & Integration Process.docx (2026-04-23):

# Fabrication and Integration Process

### 1. Material Choice Justification :

- Acrylic over MDF: Acrylic was chosen for its superior aesthetic qualities (transparency/color options) and moisture resistance. MDF, while often cheaper, is heavier and prone to swelling if exposed to moisture.
- PLA instead of Resin: PLA filament was selected for its greater durability, lower cost, and relative ease of printing with Fused Deposition Modeling (FDM) technology. PLA parts are less brittle than most Resin parts, making them ideal for functional components.

2. Fabrication Steps :

The decision to use 3D printing was based on its ability to produce accurate, complex 3D models, which would be restricted by methods like laser cutting MDF or Acrylic.

A documented "Build-log":

1. CAD Model Finalization: Review and finalize the Fusion 360 computer-aided design (CAD) models for all printable components.
2. Slicing and G-Code Generation: Use Creality Slicer software to convert the CAD files into G-code, optimizing settings for PLA filament.
3. 3D Printing Production: Print all final components on the FDM 3D printer.
4. Post-Processing: Remove support material and perform necessary cleanup, such as light sanding, on the finished parts.
5. Assembly and Integration: Integrate the 3D printed parts with other components, including heat-staking threaded inserts and mounting electronics.

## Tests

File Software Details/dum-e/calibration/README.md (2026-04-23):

# DUM-E pick calibration (approach A — measure in hardware)

Use these scripts with the **motor ESP32** on USB (same port as `DUM_E_SERIAL_PORT` in the desktop app). **Quit `mpremote` / Thonny** before running.

## Team inputs (example)

| Quantity | Example | Notes |
|---|---|---|
| Camera ↔ base (horizontal) | **28.5 in** | Use for layout / extrinsics; hand–eye still needs a calibration run. |
| Cup height | **2.39 in** | Document for CAD/IK; **grasp Z** is set by jogging, not by this number alone. |
| Cup width (grasp) | **2.25 in** | Target opening at contact — **tune close angle empirically** and record. |

**Z for pick:** Jog until fingers are at the right height, then **record** `pose_deg` for **hover** (optional) and **grasp**. Suggested **hover** is **0.5–1.0 in** above contact in joint space (achieve by small joint nudges): **hover → descend → close**.

**Gripper:** Open = max; **close** = one value per setup (or per color if you tune four). Record the 5th joint after a good grasp.

## Environment

```bash
cd /path/to/dum-e
source .venv/bin/activate
pip install -r calibration/requirements.txt

export DUM_E_SERIAL_PORT=/dev/cu.usbserial-XXXX
# export DUM_E_SERIAL_BAUD=115200
```

## Scripts (suggested order)

| Script | Purpose |
|---|---|
| `named_pose_preview.py` | Print `pose_deg` lines for `home` / `ready` / `down` from `src/robot_kinematics.py`. |
| `send_pose_deg.py` | Send one `pose_deg w u f h ee` line. |
| `jog_pose.py` | Interactive nudge per joint; updates `calibration/.last_pose.json`. |
| `record_pose.py` | Append a labeled pose to `recorded_poses.jsonl`. |

Copy `pick_constants_template.yaml` → `pick_constants.yaml` and fill angles after runs.

## Safety

- E-stop / power within reach.
- Small jog steps first (default 2°).
- Start from `ready` or `home` before moving over the table.

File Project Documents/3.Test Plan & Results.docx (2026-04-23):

# Test Plan & Results

### 1. Test Plan

Test | Method | Expected Result
Voice Commands | Speak commands through mic | System understands and responds correctly
Command Execution | Give commands (voice/text) | Robot performs the correct action
Color Detection | Place colored object in view | Camera detects the correct object
Coordinate Mapping | Compare detected vs actual position | Object position is accurate
Full Flow | Voice → detection → action | System completes the task smoothly
Usability | New user tries system | Easy to understand and use

### 2. User Testing

- Who were the users? Friends and classmates
- What tasks were given?
  - Say hello or greet the robot
  - Give simple commands like “go home”
  - Ask it to pick up a colored object
  - Try interacting freely

### 3. Results

Test | Outcome | Pass/Fail
Voice Commands | Worked after improving interpretation | Pass
Command Execution | Worked well in simulation | Pass
Color Detection | Worked in controlled setup | Pass
Coordinate Mapping | Worked digitally, not fully tested physically | Partial
Full Flow | Worked end-to-end in software | Nope
Usability | Mostly easy, slight confusion at start | Partial

### 4. Observations

- Users spoke naturally, not in exact commands
- Voice commands didn’t work initially until improved
- System felt more interactive with sound feedback
- Most testing was done digitally, less real-world testing
- Lighting affected color detection

### 6. Improvements Suggested

- Improve object detection in different lighting
- Do more physical testing and calibration
- Handle unclear commands better
- Add extra sensors for better interaction
- Make the robot more expressive and interactive

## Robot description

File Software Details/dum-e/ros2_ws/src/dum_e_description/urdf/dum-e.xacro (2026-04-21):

<?xml version="1.0" ?>
<robot name="dum-e" xmlns:xacro="http://www.ros.org/wiki/xacro">

<xacro:include filename="$(find dum_e_description)/urdf/materials.xacro" />
<xacro:include filename="$(find dum_e_description)/urdf/dum-e.trans" />
<xacro:include filename="$(find dum_e_description)/urdf/dum-e.gazebo" />
<link name="base_link">
  <inertial>
    <origin xyz="-7.764782332920779e-05 0.1609310905474023 0.014761048745804172" rpy="0 0 0"/>
    <mass value="1.3974709990038208"/>
    <inertia ixx="0.001158" iyy="0.001185" izz="0.001921" ixy="-0.0" iyz="2e-06" ixz="3e-06"/>
  </inertial>
  <visual>
    <origin xyz="0 0 0" rpy="0 0 0"/>
    <geometry>
      <mesh filename="file://$(find dum_e_description)/meshes/base_link.stl" scale="0.001 0.001 0.001"/>
    </geometry>
    <material name="silver"/>
  </visual>
  <collision>
    <origin xyz="0 0 0" rpy="0 0 0"/>
    <geometry>
      <mesh filename="file://$(find dum_e_description)/meshes/base_link.stl" scale="0.001 0.001 0.001"/>
    </geometry>
  </collision>
</link>

<link name="Upper_arm_1">
  <inertial>
    <origin xyz="-0.02962404346667396 0.049926041358079126 0.05670320856759474" rpy="0 0 0"/>
    <mass value="1.9359035819352775"/>
    <inertia ixx="0.007653" iyy="0.005008" izz="0.0039" ixy="-6.8e-05" iyz="-0.003163" ixz="-8.9e-05"/>
  </inertial>
  <visual>
    <origin xyz="0.025 -0.139 -0.0625" rpy="0 0 0"/>
    <geometry>
      <mesh filename="file://$(find dum_e_description)/meshes/Upper_arm_1.stl" scale="0.001 0.001 0.001"/>
    </geometry>
    <material name="silver"/>
  </visual>
  <collision>
    <origin xyz="0.025 -0.139 -0.0625" rpy="0 0 0"/>
    <geometry>
      <mesh filename="file://$(find dum_e_description)/meshes/Upper_arm_1.stl" scale="0.001 0.001 0.001"/>
    </geometry>
  </collision>
</link>

<link name="Waist_1">
  <inertial>
    <origin xyz="-0.004147256076267503 0.0002028414170002768 0.029023285139476503" rpy="0 0 0"/>
    <mass value="0.4246040193501383"/>
    <inertia ixx="0.000236" iyy="0.000207" izz="0.000298" ixy="-2e-06" iyz="1e-06" ixz="-2e-05"/>
  </inertial>
  <visual>
    <origin xyz="-0.0 -0.1495 -0.04" rpy="0 0 0"/>
    <geometry>
      <mesh filename="file://$(find dum_e_description)/meshes/Waist_1.stl" scale="0.001 0.001 0.001"/>
    </geometry>
    <material name="silver"/>
  </visual>
  <collision>
    <origin xyz="-0.0 -0.1495 -0.04" rpy="0 0 0"/>
    <geometry>
      <mesh filename="file://$(find dum_e_description)/meshes/Waist_1.stl" scale="0.001 0.001 0.001"/>
    </geometry>
  </collision>
</link>

<link name="Hand_1">
  <inertial>
    <origin xyz="-0.027205956143816462 -0.02890672149519427 0.005097492310937646" rpy="0 0 0"/>
    <mass value="0.7916383707029127"/>
    <inertia ixx="0.001035" iyy="0.00049" izz="0.001045" ixy="-5.2e-05" iyz="0.000101" ixz="9e-06"/>
  </inertial>
  <visual>
    <origin xyz="0.025 -0.148021 -0.321567" rpy="0 0 0"/>
    <geometry>
      <mesh filename="file://$(find dum_e_description)/meshes/Hand_1.stl" scale="0.001 0.001 0.001"/>
    </geometry>
    <material name="silver"/>
  </visual>
  <collision>
    <origin xyz="0.025 -0.148021 -0.321567" rpy="0 0 0"/>
    <geometry>
      <mesh filename="file://$(find dum_e_description)/meshes/Hand_1.stl" scale="0.001 0.001 0.001"/>
    </geometry>
  </collision>
</link>

<link name="Forearm_1">
  <inertial>
    <origin xyz="0.03220712977162327 -0.04356481414121521 0.0656408189083143" rpy="0 0 0"/>
    <mass value="2.210709102294326"/>
    <inertia ixx="0.009931" iyy="0.007224" izz="0.004389" ixy="-5e-05" iyz="0.003869" ixz="6.2e-05"/>
  </inertial>
  <visual>
    <origin xyz="0.025 -0.242392 -0.184931" rpy="0 0 0"/>
    <geometry>
      <mesh filename="file://$(find dum_e_description)/meshes/Forearm_1.stl" scale="0.001 0.001 0.001"/>
    </geometry>
    <material name="silver"/>
  </visual>
  <collision>
    <origin xyz="0.025 -0.242392 -0.184931" rpy="0 0 0"/>
    <geometry>
      <mesh filename="file://$(find dum_e_description)/meshes/Forearm_1.stl" scale="0.001 0.001 0.001"/>
    </geometry>
  </collision>
</link>

<joint name="Revolute 7" type="revolute">
  <origin xyz="-0.025 -0.0105 0.0225" rpy="0 0 0"/>
  <parent link="Waist_1"/>
  <child link="Upper_arm_1"/>
  <axis xyz="-1.0 0.0 0.0"/>
  <limit upper="1.570796" lower="-0.785398" effort="100" velocity="100"/>
</joint>

<joint name="Revolute 8" type="revolute">
  <origin xyz="0.0 0.1495 0.04" rpy="0 0 0"/>
  <parent link="base_link"/>
  <child link="Waist_1"/>
  <axis xyz="0.0 0.0 1.0"/>
  <limit upper="1.570796" lower="-1.570796" effort="100" velocity="100"/>
</joint>

<joint name="Revolute 9" type="revolute">
  <origin xyz="0.0 -0.094371 0.136636" rpy="0 0 0"/>
  <parent link="Forearm_1"/>
  <child link="Hand_1"/>
  <axis xyz="-1.0 0.0 0.0"/>
  <limit upper="1.570796" lower="-1.570796" effort="100" velocity="100"/>
</joint>

<joint name="Revolute 10" type="revolute">
  <origin xyz="0.0 0.103392 0.122431" rpy="0 0 0"/>
  <parent link="Upper_arm_1"/>
  <child link="Forearm_1"/>
  <axis xyz="1.0 0.0 0.0"/>
  <limit upper="1.570796" lower="-1.570796" effort="100" velocity="100"/>
</joint>

</robot>

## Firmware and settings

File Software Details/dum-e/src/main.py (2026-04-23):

# DUM-E entrypoint: activity/state + motion + behavior + serial input.
# Commands: dashboard / USB serial / REPL — no physical buttons by default.

import time
import select
import sys

from config import (
    BLE_DEVICE_NAME,
    LOOP_DELAY_MS,
    SLEEP_TIMEOUT_MS,
    USE_BLE_NUS,
    USE_PHYSICAL_BUTTONS,
)

from modules.recovery_timers import update_data_error_recovery, update_stop_recovery

from utils.logger import log, get_logs

from utils.timers import reset_timer, has_elapsed

from modules.state_machine import StateMachine, States

from modules.intent_parser import IntentParser

from modules.behavior_engine import BehaviorEngine

from modules.safety_manager import SafetyManager

from modules.motion_controller import MotionController

from backend.command_router import CommandRouter, build_command_from_parse_result

from backend.command_schema import Actions

state_machine = StateMachine()
intent_parser = IntentParser()
behavior_engine = BehaviorEngine()
safety_manager = SafetyManager()
motion_controller = MotionController()
last_activity_ms = reset_timer()

_ble_nus = None
if USE_BLE_NUS:
    try:
        import bluetooth

        from drivers.ble_uart_nus import BleUartNus

        _ble_nus = BleUartNus(bluetooth.BLE(), name=BLE_DEVICE_NAME)
        log("BLE NUS advertising as: " + BLE_DEVICE_NAME)
    except Exception as exc:
        log("BLE NUS init failed: " + str(exc))
        _ble_nus = None

# Give behavior engine access to servo control for expression behaviors.
behavior_engine.set_motion_controller(motion_controller)
behavior_engine.set_runtime_guards(state_machine, safety_manager)

if USE_PHYSICAL_BUTTONS:
    from drivers.panel_button import Button
    from pins import BTN_DOWN, BTN_J1, BTN_J2, BTN_J3, BTN_J4, BTN_UP

    btn_j1 = Button(BTN_J1)
    btn_j2 = Button(BTN_J2)
    btn_j3 = Button(BTN_J3)
    btn_j4 = Button(BTN_J4)
    btn_up = Button(BTN_UP)
    btn_down = Button(BTN_DOWN)
else:
    btn_j1 = btn_j2 = btn_j3 = btn_j4 = btn_up = btn_down = None

# Non-blocking serial line reader: accumulates chars until \n or \r.
_serial_poll = select.poll()
_serial_poll.register(sys.stdin, select.POLLIN)
_serial_buf = []


def boot():
    log("DUM-E booting...")
    state_machine.change_state(States.ACTIVE)
    behavior_engine.set_behavior("idle")


def mark_activity():
    global last_activity_ms

    last_activity_ms = reset_timer()
    if state_machine.is_state(States.SLEEP):
        state_machine.change_state(States.ACTIVE)
        behavior_engine.set_behavior("idle")
        log("System woke up from sleep due to activity")


# Sentiment → expression behavior mapping (GREET uses home + hand nod via set_behavior("greeting")).
_SENTIMENT_BEHAVIOR = {
    "BYE":   "express_bye",
    "HAPPY": "express_happy",
    "SAD":   "express_sad",
}


def handle_command(raw_command):
    """Parse intent → optional sentiment expression → Command → router."""
    result = intent_parser.parse(raw_command)
    command_type = result["type"]

    if command_type == "empty":
        log("Empty command ignored")
        return

    sentiment = result.get("sentiment", "NEUTRAL")
    expr_name = _SENTIMENT_BEHAVIOR.get(sentiment)
    if sentiment == "GREET":
        state_machine.change_state(States.ACTIVE)
        behavior_engine.set_behavior("greeting")
    elif sentiment == "SAD":
        state_machine.change_state(States.SAD)
        behavior_engine.run_behavior("express_sad")
    elif expr_name is not None:
        if sentiment in ("HAPPY", "BYE"):
            state_machine.change_state(States.ACTIVE)
        behavior_engine.run_behavior(expr_name)

    if command_type == "unknown":
        log("Unknown command: " + result["command"])
        return

    mark_activity()
    cmd = build_command_from_parse_result(result, source="repl")
    if cmd is None:
        log("Unhandled command path: " + str(result))
        return

    command_router.route(cmd)

    if cmd.action in (Actions.PICK_OBJECT, Actions.PLACE_OBJECT):
        behavior_engine.run_behavior("express_present")


def update_activity_state():
    if state_machine.is_state(States.ERROR):
        return
    if state_machine.is_state(States.STOP_COOLDOWN):
        return
    if state_machine.is_state(States.DATA_ERROR):
        return

    if has_elapsed(last_activity_ms, SLEEP_TIMEOUT_MS):
        if not state_machine.is_state(States.SLEEP):
            state_machine.change_state(States.SLEEP)
            behavior_engine.set_behavior("none")
            log("System entered sleep mode due to inactivity")
        return


def status_report():
    return {
        "state": state_machine.get_state(),
        "behavior": behavior_engine.get_behavior(),
        "idle_substate": behavior_engine.get_idle_substate(),
        "idle_wander_tick": behavior_engine.get_idle_wander_tick(),
        "safety": safety_manager.get_status(),
        "recent_logs": get_logs(),
    }


command_router = CommandRouter(
    motion_controller,
    state_machine,
    safety_manager=safety_manager,
    behavior_engine=behavior_engine,
    status_provider=status_report,
    history_provider=intent_parser.get_history,
)


def poll_serial():
    """Read one complete line from USB stdin within ~LOOP_DELAY_MS.

    A zero-timeout poll often misses USB CDC input on some ESP32 MicroPython
    builds; blocking for short slices lets the REPL/VCP driver deliver bytes.
    """
    global _serial_buf

    deadline = time.ticks_add(time.ticks_ms(), LOOP_DELAY_MS)
    while time.ticks_diff(deadline, time.ticks_ms()) > 0:
        wait_ms = time.ticks_diff(deadline, time.ticks_ms())
        if wait_ms > 50:
            wait_ms = 50
        if wait_ms <= 0:
            break
        events = _serial_poll.poll(wait_ms)
        if not events:
            continue
        while True:
            char = sys.stdin.read(1)
            if not char:
                break
            if char in ("\n", "\r"):
                if _serial_buf:
                    line = "".join(_serial_buf)
                    _serial_buf = []
                    return line
            else:
                _serial_buf.append(char)
            if not _serial_poll.poll(0):
                break
    return None


def handle_buttons():
    """Manual joint select + nudge — only when USE_PHYSICAL_BUTTONS is True."""
    if not USE_PHYSICAL_BUTTONS:
        return

    if btn_j1.pressed():
        motion_controller.select_joint(0)
        mark_activity()
    if btn_j2.pressed():
        motion_controller.select_joint(1)
        mark_activity()
    if btn_j3.pressed():
        motion_controller.select_joint(2)
        mark_activity()
    if btn_j4.pressed():
        motion_controller.select_joint(3)
        mark_activity()

    if btn_up.held():
        motion_controller.nudge_joint(+1)
        mark_activity()
    elif btn_down.held():
        motion_controller.nudge_joint(-1)
        mark_activity()


def loop():
    t0 = time.ticks_ms()
    if _ble_nus is not None:
        for ln in _ble_nus.pull_lines():
            handle_command(ln)
    line = poll_serial()
    if line:
        handle_command(line)

    handle_buttons()
    update_stop_recovery(state_machine, safety_manager, motion_controller, behavior_engine)
    update_data_error_recovery(state_machine, safety_manager, motion_controller, behavior_engine)
    update_activity_state()
    motion_controller.update()
    behavior_engine.update()
    elapsed = time.ticks_diff(time.ticks_ms(), t0)
    rest = LOOP_DELAY_MS - elapsed
    if rest > 0:
        time.sleep_ms(rest)


boot()

while True:
    loop()

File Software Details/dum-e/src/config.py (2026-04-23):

"""DUM-E System Configuration. Tune after hardware and behavior testing."""

# =========================
# DUM-E System Configuration
# MicroPython-only constants
# =========================

# Main loop — ~0.04 s matches hardware “smooth scan” (30–50 ms).
LOOP_DELAY_MS = 40

# Physical panel buttons — current hardware has none; control via dashboard / USB serial / REPL.
USE_PHYSICAL_BUTTONS = False

# All arm joints: PCA9685 (I2C) when True, or four GPIOs when False — see pins.py.
USE_PCA9685 = True

# Nordic UART Service (BLE) for commands from laptop — set True only if you use BLE.
# False: USB/serial only (no bluetooth import; avoids OSError on builds/boards with flaky BLE).
USE_BLE_NUS = False
BLE_DEVICE_NAME = "DUM-E"

# Motion: exponential smoothing per loop — current += (target - current) * k (see motion_controller).
MOTION_SMOOTHING = 0.10
# Jitter: within this many ° of target, treat as reached (avoids micro-twitch).
MOTION_DEADZONE_DEG = 1.0
# On boot, ease from this pose to JOINT_HOME_ANGLES (set False to start already at home).
USE_BOOT_MOTION_SMOOTH = True
BOOT_MOTION_FROM_DEG = [90, 90, 90, 90]

# Command system
COMMAND_HISTORY_SIZE = 5  # Rolling window of normalized commands for 'history'
MAX_LOG_ENTRIES = 10  # Ring buffer depth in utils.logger

# Activity / sleep timing (single tier: inactivity → SLEEP, no IDLE state)
SLEEP_TIMEOUT_MS = 300_000  # ms without activity before ACTIVE → SLEEP (e.g. 5 minutes)

# Idle "look around" — new random targets every few seconds (behavior "idle", state ACTIVE)
IDLE_WANDER_MIN_MS = 3_000
IDLE_WANDER_MAX_MS = 6_000
# Per-joint (waist, upper, forearm, hand) random target ranges in ° — bias upward, hardware ref.
IDLE_LOOK_JOINT_RANGES = (
    (100, 130),  # base
    (100, 125),  # shoulder
    (105, 135),  # elbow
    (95, 115),   # head
)
IDLE_INSPECT_NOD_SWING_DEG = 15
IDLE_INSPECT_PHASE_MS = 280
IDLE_INSPECT_SETTLE_MS = 400

# STOP: move home → estop hold at home → auto clear after this (ms)
STOP_COOLDOWN_MS = 10_000

# Bad data / fault: error nod then auto home + idle after this (ms) from fault entry
DATA_ERROR_RECOVERY_MS = 5_000

# Motion / behavior timing
GREET_SEQUENCE_TIMEOUT_MS = 12_000  # safety cap for home + hand-nod greet FSM
THINKING_DURATION_MS = 1_500  # ms thinking_behavior runs before auto-idle

# Dance behavior: beat length × steps loops until DANCE_DURATION_MS
DANCE_BEAT_MS = 320
DANCE_DURATION_MS = 10_000

# Sad expression: droop → hold → either sad_hold (if state SAD) or recover to pre-expression pose
SAD_PEAK_HOLD_MS = 2_500
SAD_RETURN_EASE_MS = 1_200
WAKE_COOLDOWN_MS = 3_000  # ms reserved for post-wake debounce (future use)

# Kinematics — aligned with dum_e_description/urdf/dum-e.xacro via robot_kinematics
NUM_JOINTS = 4

# Mechanical home / default scan pose (°) — hardware reference: [110, 110, 115, 105].
# Single source: `robot_kinematics.UPRIGHT_FIRMWARE_DEG` (re-imported below).
UPRIGHT_POSE_DEG = [110, 110, 115, 105]
JOINT_HOME_ANGLES = list(UPRIGHT_POSE_DEG)
SAD_SLOUCH_UPPER_DEG = 28
SAD_SLOUCH_FOREARM_DEG = 118
SAD_SLOUCH_HAND_DEG = 72

try:
    from robot_kinematics import UPRIGHT_FIRMWARE_DEG, sad_slouch_firmware_deg

    UPRIGHT_POSE_DEG = list(UPRIGHT_FIRMWARE_DEG)
    JOINT_HOME_ANGLES = list(UPRIGHT_FIRMWARE_DEG)
    _sad_slouch = sad_slouch_firmware_deg()
    SAD_SLOUCH_UPPER_DEG = _sad_slouch[1]
    SAD_SLOUCH_FOREARM_DEG = _sad_slouch[2]
    SAD_SLOUCH_HAND_DEG = _sad_slouch[3]
except (ImportError, Exception):
    pass

# Software joint limits (degrees) — set to match mechanical stops after assembly.
JOINT_ANGLE_MIN_DEG = [0, 0, 0, 0]
JOINT_ANGLE_MAX_DEG = [180, 180, 180, 180]

# Per-joint PWM pulse width calibration (µs) — tune so 0°/180° match mechanics.
# Defaults are typical hobby servos; measure each joint after wiring (see docs/firmware_setup.md).
SERVO_PWM_MIN_US = [500, 500, 500, 500]
SERVO_PWM_MAX_US = [2500, 2500, 2500, 2500]

# Debug
DEBUG = True

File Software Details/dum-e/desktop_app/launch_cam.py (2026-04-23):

"""launch_cam.py — one-command camera bringup.

Usage:
    python desktop_app/launch_cam.py

What it does:
    1. Prompts for WiFi SSID + password (or reads WIFI_SSID / WIFI_PASS env vars)
    2. Opens the ESP32-CAM serial port directly via pyserial (no mpremote)
    3. Pastes the stream-server script into the MicroPython REPL line by line
    4. Waits until the board prints its IP address
    5. Launches vision_preview.py pointed at that IP

Press Ctrl+C at any time to shut everything down.
"""

import os
import re
import subprocess
import sys
import threading
import time

try:
    import serial
except ImportError:
    print("ERROR: pyserial not installed. Run:  pip install pyserial")
    sys.exit(1)

# ---------------------------------------------------------------------------
# Config
# ---------------------------------------------------------------------------

PORT      = "/dev/tty.usbserial-10"
BAUD      = 115200
STREAM_PORT = 81
FRAME_SIZE  = "camera.FRAME_QVGA"   # 320×240 — good balance of speed vs quality
WIFI_TIMEOUT_S = 20                  # seconds the board waits to join WiFi
IP_TIMEOUT_S   = WIFI_TIMEOUT_S + 10 # total host-side wait for CAM_IP line

# ---------------------------------------------------------------------------
# MicroPython stream-server — pasted into the live REPL
# ---------------------------------------------------------------------------

def build_script(ssid: str, password: str) -> str:
    """Return the complete MicroPython script as a single string."""
    return f"""\
import network, socket, camera, time

wifi = network.WLAN(network.STA_IF)
wifi.active(True)
wifi.connect({ssid!r}, {password!r})

dl = time.ticks_add(time.ticks_ms(), {WIFI_TIMEOUT_S * 1000})
while not wifi.isconnected():
    if time.ticks_diff(dl, time.ticks_ms()) <= 0:
        print('WIFI_FAIL')
        raise SystemExit
    time.sleep(0.2)

ip = wifi.ifconfig()[0]
print('CAM_IP:' + ip)

# QVGA + quality: smaller JPEG = less Wi‑Fi choppiness; quality 20 (typ. 10–63) = smaller payload
# If your port errors here, use camera.init(0, format=camera.JPEG, framesize={FRAME_SIZE}) only.
try:
    camera.init(0, format=camera.JPEG, framesize={FRAME_SIZE}, quality=20)
except TypeError:
    camera.init(0, format=camera.JPEG, framesize={FRAME_SIZE})

srv = socket.socket()
srv.setsockopt(socket.SOL_SOCKET, socket.SO_REUSEADDR, 1)
srv.bind(('', {STREAM_PORT}))
srv.listen(1)
print('STREAM_READY')

while True:
    conn, _ = srv.accept()
    conn.send(b'HTTP/1.1 200 OK\\r\\nContent-Type: multipart/x-mixed-replace; boundary=frame\\r\\n\\r\\n')
    try:
        while True:
            img = camera.capture()
            conn.send(b'--frame\\r\\nContent-Type: image/jpeg\\r\\n\\r\\n' + img + b'\\r\\n')
    except:
        conn.close()
"""

# ---------------------------------------------------------------------------
# Serial REPL helpers
# ---------------------------------------------------------------------------

def wait_for_prompt(ser: serial.Serial, timeout: float = 5.0) -> bool:
    """Drain input until we see '>>> ', return True on success."""
    deadline = time.time() + timeout
    buf = b""
    while time.time() < deadline:
        chunk = ser.read(ser.in_waiting or 1)
        buf += chunk
        if b">>> " in buf or b"... " in buf:
            return True
    return False


def send_line(ser: serial.Serial, line: str):
    ser.write((line + "\r\n").encode())
    time.sleep(0.05)   # small gap so the board can echo + process


def read_output(ser: serial.Serial,
                collected: list[str],
                stop: threading.Event):
    """Background thread: read serial bytes, split into lines, print + collect."""
    buf = ""
    while not stop.is_set():
        try:
            raw = ser.read(ser.in_waiting or 1)
        except Exception:
            break
        if not raw:
            continue
        buf += raw.decode(errors="replace")
        while "\n" in buf:
            line, buf = buf.split("\n", 1)
            line = line.strip("\r")
            if line:
                print(f"[ESP32-CAM] {line}")
                collected.append(line)

# ---------------------------------------------------------------------------
# Credential helper
# ---------------------------------------------------------------------------

def get_wifi_credentials() -> tuple[str, str]:
    ssid = os.environ.get("WIFI_SSID") or input("WiFi SSID: ").strip()
    pwd  = os.environ.get("WIFI_PASS") or input("WiFi Password: ").strip()
    return ssid, pwd

# ---------------------------------------------------------------------------
# Main
# ---------------------------------------------------------------------------
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

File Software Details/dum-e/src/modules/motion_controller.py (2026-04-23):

from drivers.servo import Servo

from utils.logger import log

from config import (
    BOOT_MOTION_FROM_DEG,
    JOINT_ANGLE_MAX_DEG,
    JOINT_ANGLE_MIN_DEG,
    JOINT_HOME_ANGLES,
    MOTION_DEADZONE_DEG,
    MOTION_SMOOTHING,
    NUM_JOINTS,
    SERVO_PWM_MAX_US,
    SERVO_PWM_MIN_US,
    UPRIGHT_POSE_DEG,
    USE_BOOT_MOTION_SMOOTH,
    USE_PCA9685,
)

from pins import (
    PCA9685_ADDR,
    PCA9685_CH_FOREARM,
    PCA9685_CH_HAND,
    PCA9685_CH_UPPER_ARM,
    PCA9685_CH_WAIST,
    PCA9685_I2C_ID,
    PCA9685_SCL,
    PCA9685_SDA,
    SERVO_FOREARM,
    SERVO_HAND,
    SERVO_UPPER_ARM,
    SERVO_WAIST,
)

try:
    from robot_kinematics import firmware_deg_for_named_pose, NAMED_POSE_KEYS
except ImportError:
    firmware_deg_for_named_pose = None
    NAMED_POSE_KEYS = ("home", "ready", "down")


class MotionController:
    """Four-DOF arm. Joint order: waist, upper_arm, forearm, hand."""

    def __init__(self):
        self.servos = []
        if USE_PCA9685:
            from machine import I2C, Pin

            from drivers.pca9685 import PCA9685

            _i2c = I2C(
                PCA9685_I2C_ID,
                scl=Pin(PCA9685_SCL),
                sda=Pin(PCA9685_SDA),
                freq=400_000,
            )
            _pca = PCA9685(_i2c, PCA9685_ADDR)
            pca_channels = [
                PCA9685_CH_WAIST,
                PCA9685_CH_UPPER_ARM,
                PCA9685_CH_FOREARM,
                PCA9685_CH_HAND,
            ]
            for i in range(NUM_JOINTS):
                self.servos.append(
                    Servo(
                        pca9685=_pca,
                        channel=pca_channels[i],
                        min_us=SERVO_PWM_MIN_US[i],
                        max_us=SERVO_PWM_MAX_US[i],
                    )
                )
        else:
            pins = [
                SERVO_WAIST,
                SERVO_UPPER_ARM,
                SERVO_FOREARM,
                SERVO_HAND,
            ]
            for i in range(NUM_JOINTS):
                self.servos.append(
                    Servo(
                        pins[i],
                        min_us=SERVO_PWM_MIN_US[i],
                        max_us=SERVO_PWM_MAX_US[i],
                    )
                )
        self.joint_names = [
            "waist",
            "upper_arm",
            "forearm",
            "hand",
        ]
        home = [self._clamp_joint(i, a) for i, a in enumerate(JOINT_HOME_ANGLES)]
        if USE_BOOT_MOTION_SMOOTH and len(BOOT_MOTION_FROM_DEG) == NUM_JOINTS:
            self.current_angles = [self._clamp_joint(i, BOOT_MOTION_FROM_DEG[i]) for i in range(NUM_JOINTS)]
        else:
            self.current_angles = list(home)
        self.target_angles = list(home)
        self._smooth = float(MOTION_SMOOTHING)
        self._deadzone = float(MOTION_DEADZONE_DEG)
        self.poses = {}
        for name in NAMED_POSE_KEYS:
            if firmware_deg_for_named_pose is not None:
                raw = firmware_deg_for_named_pose(name)
            elif name == "home":
                raw = list(UPRIGHT_POSE_DEG)
            elif name == "ready":
                u = UPRIGHT_POSE_DEG
                raw = [u[0], 60, 120, u[3]]
            else:
                u = UPRIGHT_POSE_DEG
                raw = [u[0], 120, 140, u[3]]
            self.poses[name] = [self._clamp_joint(i, raw[i]) for i in range(NUM_JOINTS)]
        self.selected_joint = None
        for i in range(NUM_JOINTS):
            self.servos[i].write(self.current_angles[i])
        log("Motion controller initialized (smooth k=" + str(self._smooth) + " deadzone=" + str(self._deadzone) + "°)")

    def _clamp_joint(self, joint_idx, angle):
        lo = JOINT_ANGLE_MIN_DEG[joint_idx]
        hi = JOINT_ANGLE_MAX_DEG[joint_idx]
        a = float(angle)
        if a < lo:
            return lo
        if a > hi:
            return hi
        return a

    def select_joint(self, joint_id):
        if joint_id < 0 or joint_id >= NUM_JOINTS:
            log("Invalid joint_id: " + str(joint_id))
            return
        self.selected_joint = joint_id
        log("Selected joint: " + self.joint_names[joint_id])

    def nudge_joint(self, direction, step=5):
        if self.selected_joint is None:
            return
        idx = self.selected_joint
        new_angle = self.current_angles[idx] + (step * direction)
        new_angle = self._clamp_joint(idx, new_angle)
        self.current_angles[idx] = new_angle
        self.target_angles[idx] = new_angle
        self.servos[idx].write(new_angle)
        log("[NUDGE] " + self.joint_names[idx] + " -> " + str(new_angle))

    def move_to_pose(self, angles):
        if len(angles) != NUM_JOINTS:
            return
        self.target_angles = [self._clamp_joint(i, angles[i]) for i in range(NUM_JOINTS)]
        log("Moving to pose: " + str(self.target_angles))

    def move_to_named_pose(self, name):
        if name not in self.poses:
            log("Unknown pose: " + str(name))
            return
        angles = self.poses[name]
        log("Moving to named pose: " + name)
        self.move_to_pose(angles)

    def update(self):
        k = self._smooth
        dz = self._deadzone
        for i in range(NUM_JOINTS):
            c = float(self.current_angles[i])
            t = float(self.target_angles[i])
            err = t - c
            if abs(err) <= dz:
                if abs(c - t) > 1e-6:
                    c = t
                    self.current_angles[i] = c
                    self.servos[i].write(c)
                continue
            c = c + err * k
            if abs(t - c) <= dz:
                c = t
            c = self._clamp_joint(i, c)
            self.current_angles[i] = c
            self.servos[i].write(c)

    def is_at_target(self):
        """True when every joint has reached its commanded target (for STOP cooldown / recovery)."""
        dz = self._deadzone
        for i in range(NUM_JOINTS):
            if abs(float(self.current_angles[i]) - float(self.target_angles[i])) > dz:
                return False
        return True

    def get_pose(self):
        return self.current_angles

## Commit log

2026-04-01 Add DUM-E ESP32 MicroPython robotic arm project
    Add Software Details/dum-e: modular firmware layout (main, config, pins,
    utils, driver stubs, modules, interface placeholders), documentation
    (hardware, pin map, architecture, state machine, notes), test scaffolds,
    and mpremote deploy scripts (common.sh resolves venv python -m mpremote).
    Include requirements.txt for host tooling and project .gitignore (excludes .venv).
    Made-with: Cursor
    [behavior_engine.py, command_parser.py, config.py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]
2026-04-08 feat(dum-e): tick-based timers, state machine, and config for behavior timing
    - Add timers helpers: current_millis, elapsed_ms (ticks_diff), has_elapsed,
    reset_timer, sleep_ms for idle/sensor/cooldown patterns
    - Expand StateMachine: BOOT start, logged transitions, same-state no-op,
    is_state, reset; integrate utils.logger
    - Logger: DEBUG-gated output, ring buffer capped by MAX_LOG_ENTRIES,
    get_logs/clear_logs
    - Config: loop interval, idle/sleep timeouts, sensor/motion durations,
    distance thresholds, DEBUG flag
    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
    [config.py, state_machine.py]
2026-04-08 DUM-E: core firmware stack, drivers, and commented modules
    Add state machine, command parser, behavior engine, safety manager, serial
    interface stub, and main loop with activity/idle/sleep and status report.
    Replace stepper/pir driver files with Servo and Button (MicroPython). Extend
    config, timers, logger, and motion_controller skeleton. Include oops.py arm demo.
    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
    [behavior_engine.py, command_parser.py, config.py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]
2026-04-15 feat(dum-e): firmware loop, command router, and RobotBridge module
    - Wire main loop: buttons, activity timeouts, motion, behavior, command path
    - Add backend command schema/router and IntentParser; extend CommandParser
    - MotionController servos, poses, joint select/nudge; behavior_engine timing
    - Add interfaces/robot_bridge for laptop/ROS String commands and state mirror
    - Add oops.py standalone servo demo (GPIO layout documented)
    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
2026-04-15 feat(dum-e): Flask dashboard, ROS state manager, deploy tooling
    - Add backend_server: Flask app, dum_e_runtime bridge to CommandRouter, dashboard UI
    - Add ros2_ws dum_e_controller: /dum_e_command subscriber, /joint_states publisher
    - Extend deploy scripts (mpremote resolution, repl/sync helpers); setup-host.sh for venv
    - Add scripts/verify_stack.py for local integration checks; refresh README
    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
2026-04-20 refactor(dum-e): repo cleanup and desktop_app consolidation
    - Delete all stub drivers (buzzer, ultrasonic, tof_sensor), stub interfaces
    (serial, bluetooth, web), empty perception module, and empty test scaffolds
    - Delete deprecated_web_ui, backend_server Flask layer, scratch files,
    empty placeholder dirs (src/app, src/core, src/data, tools), and stale docs
    - Move backend_server/services/ into desktop_app/services/ and delete
    backend_server/ entirely; rewire app_runtime.py to use direct relative imports
    - Collapse src/pins.py to only the 8 pins actively used in code
    - Fix stale docstrings across __init__ files after removed modules
    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
    [ai_interpreter.py, app.py, app_runtime.py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]
2026-04-21 DUM-E: ROS2 description, vision stack, firmware docs, hardware URDF
    - Add dum_e_description (URDF, meshes, view_robot launch, build_ros.sh)
    - Remap joint_states in dum_e_state_manager to URDF Revolute 7-10 + end_effector
    - Desktop vision services, launch_cam, test_vision; runtime updates
    - Firmware/config/motion updates; docs for hardware, firmware, roles
    - dum_hardware STLs and URDF; parent dum_hardware README
    - Repo .gitignore: DS_Store, exclude large desktop_app/sounds binaries
    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
    [Base.stl, Forearm.stl, Forearm_1.stl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]
2026-04-21 dum-e: desktop runtime, vision idle, kinematics, state machine, docs
    - Extend desktop app services (AI interpreter, sound, runtime, status panel)
    - Add vision_idle service and robot_kinematics; URDF poses for controller
    - Update backend command routing/schema, behavior and motion control
    - Refresh architecture, hardware, firmware, and state machine docs
    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
2026-04-21 DUM-E: safety cooldowns, vision (FFmpeg/buffer), docs and firmware notes
    - STOP_COOLDOWN and DATA_ERROR flows with recovery_timers; panel_button rename
    - camera_stream: CAP_FFMPEG, buffer=1, robust read; vision_runtime kwargs; _wsl re-exports
    - launch_cam: optional JPEG quality=20; firmware_esp32cam Arduino/MicroPython notes
    - Docs and desktop status colors aligned with new states
    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
2026-04-22 Add ROS 2 track_target_node for /dume/target_coord → dum_e_runtime
    - Subscribes to geometry_msgs/Point; x centering, z as area, move_to left/right/forward
    - Gripper-in-place when area >= 12000; command rate limit; standard rclpy spin
    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
2026-04-22 track_target_node: FSM with debounced grip latch, 5s hold, random place pose
    - TRACKING -> HELD_PICKED after centered+area streak; ignore vision while held
    - Timer fires one move_to to random pose in _RANDOM_PLACE_POSES after 5s
    - Return to TRACKING; one-shot place via _place_pending
    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
2026-04-23 Sync project: documents, dum-e software, calibration, media, and hardware cleanup
    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
    [Base.stl, Forearm.stl, Hand.stl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]
